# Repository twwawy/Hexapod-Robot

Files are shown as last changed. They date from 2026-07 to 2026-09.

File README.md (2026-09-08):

<div align="center">

# 모듈형 재난대응 6족 로봇

### Physical AI 기반 험지 이동·환경 인식·임무 확장 플랫폼







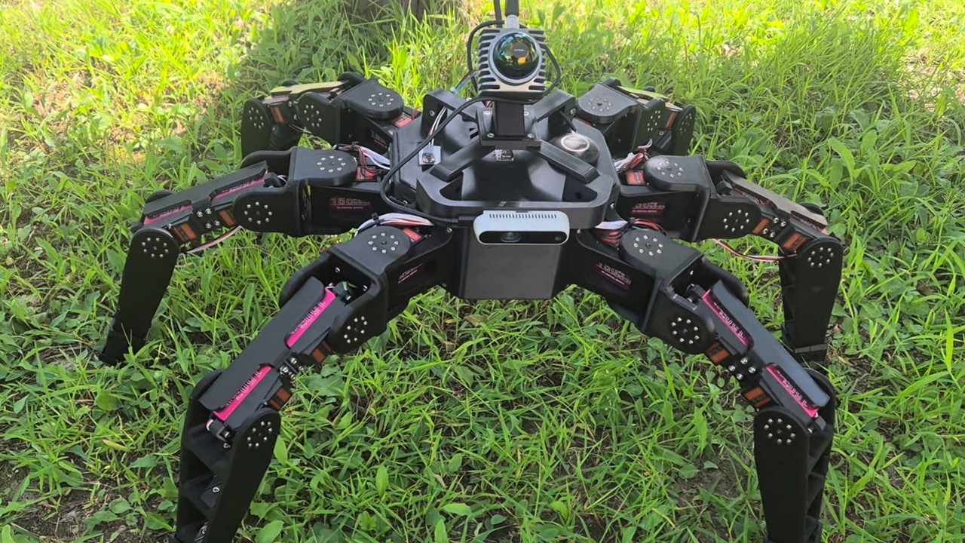
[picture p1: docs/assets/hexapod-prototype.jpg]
모듈형 재난대응 6족 로봇 시제품


</div>

## 통합 v4: 시작과 문서

**조종기 전제 학습 추가: [RC 명령 추종 학습](docs/ADAPTIVE_RC_TRAINING.md)**.
`--profile rc`는 전진·후진·yaw·정지 전환을 학습하며 command 성공과 계단 완주를 구분한다.
현재 RC curriculum은 평지 Tripod/Wave/Hybrid이다. 지형 등판과 혼합한 실기 조종 성능은 미검증이다.
RC 첫 학습은 기존 계단 checkpoint의 `--restore` 없이 시작한다. curriculum shell 명령은
commit별 독립 worktree에서 실행하여 개발 중 코드 변경이 다음 retry에 섞이지 않게 한다.

**최신: [phase 경계 재접촉 복구·70% 통과까지 재시도](docs/ADAPTIVE_RECONTACT.md)**.
MJX에서 대기 중 접촉이 끊긴 발만 제한적으로 내려 복구한다. GT 높이 계산/잔차 범위는
유지한다. curriculum 기본값은 완주율 70%를 통과해야 다음 지형으로 진행하며 무제한 재시도를 지원한다.

**현재 추천 학습: [GT teacher curriculum](docs/ADAPTIVE_GT_TEACHER.md)**.
정확한 지형으로 먼저 학습하고 cycle마다 zero-action/best-policy를 같은 seed로 비교한다.
기존 cycle별 W&B best score/영상은 유지한다. 실행은 사용자에게 맡긴다.
경사면 기존 checkpoint에서 [완주 보상으로 재개](docs/ADAPTIVE_COMPLETION_REWARD.md)할 수 있다.
잔차 범위 유지, 완주율 우선 best 선택, 최대 40초 영상과 마지막 5초 진단,
재시도·승급 정책은 위 최신 재접촉 문서의 70% 통과 기준을 따른다.

**최신 변경: elevation grid CNN 관측 v5** — 24-D 물리 action/SPI는 v4를 유지하지만,
정책은 24×24×6 로컬 지도를 CNN으로 읽는다. 지도 극값 누적·보폭 선호 때문에 발생하는
HOLD를 수정하고 보행 전환 지속 확인과 W&B 정지 시간 지표를 추가했다.
**기존 checkpoint와 입력/network가 달라 새 학습이 필요하다. 이번 변경의 학습·시뮬레이션은
실행하지 않았다.** [변경 범위·새 학습 명령·확인 항목](docs/ADAPTIVE_ELEVATION_GRID_V5.md)

현재 작업 브랜치 `codex/adaptive-hybrid-rl-integration`은 최신 main에서 시작해 adaptive MJX를
선택적으로 가져왔다. Full merge는 하지 않았다. **코드 통합과 portable 계약 검사까지 진행했으며,
계단 등판·PPO·STM32 보드 동작은 아직 검증하지 않았다.**

| 카테고리 | 문서 / 실행 경로 |
|---|---|
| 통합 architecture·24-D/관측·변경 내용·남은 위험 | [v4 통합 설명](docs/ADAPTIVE_INTEGRATION_V4.md) |
| 브랜치 분석·파일 출처 | [사전 분석](docs/ADAPTIVE_INTEGRATION_ANALYSIS.md), [전체 변경 파일](docs/ADAPTIVE_INTEGRATION_FILES.md) |
| Stage0 viewer·표시·조작 | [viewer 사용법](docs/HEXAPOD_MJX_ADAPTIVE_GAIT_USAGE.md) |
| 학습 단계 | [학습 계획](docs/HEXAPOD_MJX_ADAPTIVE_GAIT_LEARNING_PLAN.md) |
| 짧은 평지 cycle 반복·cycle별 W&B score/영상 | [실행 명령 및 저장 규칙](docs/ADAPTIVE_OBSERVE_CYCLES.md) |
| Rough hfield 오류 수정·평지 가중치에서 재개 | [adaptive box 지형과 명시적 이전](docs/ADAPTIVE_ROUGH_BOXES.md) |
| 수 회 Tripod 후 정지·영상 종료 수정 | [원인·수정·사용자 검증 명령](docs/TRIPOD_STOP_FIX.md) |
| Jetson ↔ STM32 wire | [SPI v3](docs/ADAPTIVE_SPI_V3.md) |
| STM32 실제 contact/Wave 기준 | [Wave gait](SW/STM32/WAVE_GAIT.md) |
| 기존 18-D replay | `scripts/view_trained_policy.sh`, 기존 `mjx/firmware_mjx_controller.py` |

```bash
cd /home/huro/Hexapod-Robot-integration
source /home/huro/.venvs/hexapod-mjx/bin/activate
bash scripts/view_foothold_planner.sh --controller adaptive --terrain flat --perception oracle
bash scripts/view_foothold_planner.sh --controller adaptive --terrain steps --perception oracle
bash scripts/view_foothold_planner.sh --controller adaptive --terrain steps --perception lidar --stage0 --speed 0.04
```

먼저 flat의 zero-action Tripod, 계단의 candidate/reference/selected/latched marker,
short-step·Wave 전환과 unknown HOLD를 확인한다. 이후 학습/오프라인 Jetson/ARM 빌드는
[순서별 명령](docs/ADAPTIVE_INTEGRATION_V4.md#사용자-실행-순서)을 사용한다.
방향키 포커스 문제가 있으면 `W/S`로 전후, `A/D`로 회전할 수 있다. 키가 들어오면 콘솔에
`command: vx=...`가 즉시 출력된다. `--speed 0.04`는 키 입력 없이 시작 명령을 넣는다.

## 프로젝트 소개

본 프로젝트는 붕괴 구조물, 잔해, 경사면, 단차와 계단처럼 사람이 직접 접근하기 어려운 재난 현장을 선행 탐색하기 위한 6족 보행 로봇이다. 하나의 공통 보행 플랫폼 위에 센서와 작업 장비를 교체할 수 있는 모듈형 구조를 적용하여, 환경 매핑·자율 탐색·현장 조작·구호물품 전달 등 임무별 구성을 목표로 한다.

6개의 독립적인 3자유도 다리와 총 18개의 관절을 사용하며, **Geometry가 지형과 가능한 영역을 계산하고, 강화학습이 foothold·clearance·몸체 자세/높이·보폭·trajectory timing을 최적화하며 STM32가 접촉과 실행 안전을 담당하는 계층형 제어 구조**를 채택하였다. Jetson은 SLAM·환경 인식·경로계획·강화학습 등 상위 연산을, STM32는 200 Hz 주기의 발끝 궤적·역기구학·서보 제어를 담당하도록 분리하였다.

> [!NOTE]
> 이 저장소는 구현 코드, 설계 자료, 시뮬레이션 결과와 개발 문서를 함께 관리한다. 기능별 완성도와 검증 수준이 다르므로 아래의 **현재 구현 상태**와 각 문서의 검증 범위를 확인해야 한다.

## 핵심 특징

| 영역 | 주요 내용 |
|---|---|
| **험지 보행** | Tripod Gait, 3차 Bézier 발끝 궤적, 3자유도 역기구학, 18개 서보모터 제어 |
| **접촉 적응** | 6개 FSR 접촉 상태 기반 Early Landing·Late Landing 보정과 작업영역 제한 |
| **계층형 Physical AI** | Classical Controller의 발끝 목표에 제한된 Cartesian Residual을 더하는 강화학습 구조 |
| **환경 인식** | Livox MID-360, RealSense D435, IMU를 이용한 3차원 인식·SLAM·경로계획 구조 |
| **분산 제어** | Jetson 상위 판단과 STM32 실시간 보행 제어 분리, 128바이트 SPI v3 실행/관측 프레임 |
| **모듈형 임무 확장** | 센서 위치 변경, 열화상·가스 센서, 매니퓰레이터, 구급·적재 모듈 확장 고려 |
| **원격 운용** | 위치·자세·통신·이동 경로 모니터링과 목적지·모드·비상 정지 명령 구조 |

## 시스템 구성

<div align="center">
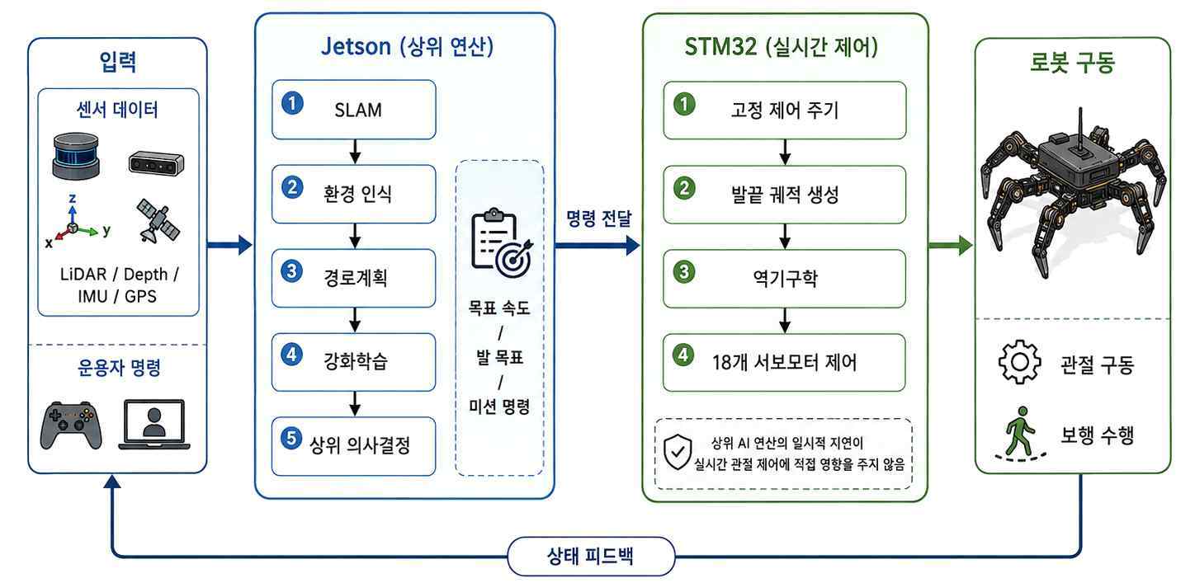
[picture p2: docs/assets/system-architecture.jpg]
Jetson과 STM32 기반 분산 제어 시스템 구조
  
</div>

```text
LiDAR / Depth Camera / IMU / 운용자 명령
                    │
                    ▼
Jetson Orin Nano Super
SLAM → 환경 인식 → 경로계획 → 강화학습·상위 의사결정
                    │  목표 속도·발 목표·임무 명령
                    ▼
STM32 NUCLEO-F446RE
고정 제어 주기 → 발끝 궤적 → 3DOF IK → 18개 서보 제어
                    │
                    ▼
              6족 로봇 구동
                    │  관절각·접촉·IMU 상태
                    └──────────────────────► Jetson / 관제 시스템
```

### STM32 ↔ Jetson 통신

통합 브랜치는 **SPI v3, 128 bytes**를 기본으로 사용한다. 최종 AdaptiveExecutionPlan을
explicit little-endian fixed point로 전달하고 CRC·session·sequence·observation age·plan을 검증한다.
상태와 계획 상세는 같은 시점의 두 observation page로 제공한다. 기존 v2 codec은 보존하지만
v2 master와 기본 v3 app은 호환되지 않는다. 실제 DMA/DRDY 운용은 사용자 검증 대상이다.

- [SPI v3 정확한 offset·단위·CRC](docs/ADAPTIVE_SPI_V3.md)
- [기존 v2 문서](SW/STM32/STM32-Jetson%20SPI%2032바이트%20패킷%20프로토콜.md)

## 보행 및 지형 적응 제어

### 1. Classical Controller

세 다리가 지면을 지지하는 동안 나머지 세 다리를 이동시키는 Tripod Gait를 사용한다. 스윙 발의 경로는 3차 Bézier 곡선으로 생성하고, 발끝 목표 좌표를 각 다리의 3자유도 역기구학으로 관절 목표각으로 변환한다. 작업영역과 IK 유효성을 검사하여 비정상적인 관절 명령이 출력되지 않도록 제한한다.

### 2. FSR 접촉 보정

- **Early Landing:** 예상보다 먼저 접촉하면 스윙을 종료하고 지지 상태로 전환
- **Late Landing:** 예정된 착지 시점에도 미접촉이면 발끝을 추가 하강하여 지면 탐색
- **기준 높이 보정:** 접촉 보정이 반복되어 몸체 높이가 누적 변화하지 않도록 기준값 보정

### 3. Adaptive residual policy 24-D v4

Wide25 후보에서 safe reference를 찾고, 별도 local25 후보에서 RL의 **X ±6 cm / Y ±4 cm**
요청을 안전한 endpoint로 projection한다. Terrain Z는 geometry가 결정한다.
6개 clearance, roll/pitch/body height, stride 및 apex/transfer timing도 policy가 조절한다.
Supervisor는 **Tripod normal → short-step → Wave → HOLD** 순서로 결정한다.
UNKNOWN은 즉시 Wave로 보내지 않는다. 학습 가중치 없이 zero-action Stage0부터 확인한다.

## 모듈형 재난 대응 시나리오

하나의 6족 플랫폼을 임무에 맞춰 재구성하는 것이 프로젝트의 핵심 방향이다.

| 구성 | 역할 | 현재 범위 |
|---|---|---|
| **LiDAR·IMU 모듈** | 3D 지도 생성, 위치·자세 추정, 자율 탐색 | 하드웨어·시스템 구조 개발 |
| **센서 위치 변경** | 고정형 LiDAR의 사각지대 보완, 목적별 공간 정보 수집 | 장착 구조 확장 방향 |
| **매니퓰레이터** | 문 개방, 가벼운 장애물 이동, 현장 작업 | 확장 모듈·실물 통합 검증 필요 |
| **구급·적재 모듈** | 구급상자, 센서와 필수 물품 전달 | 확장 제안 |
| **열화상·가스 센서** | 인명·열원 탐색, 유해 환경 측정 | 확장 제안 |

```text
현장 투입 → 환경 인식·지도 생성 → 통과 가능성 판단
         → 자율주행·험지 이동 → 현장 조작 또는 물자 전달
         → 상태 보고·필요 시 원격 개입
```

## 현재 구현 및 검증 상태

| 항목 | 상태 | 검증 범위 |
|---|---|---|
| 6족 기구·18자유도 구동부 | 제작 | Fusion 360, 분리형 다리·몸체·센서 장착부 |
| STM32 기본 보행 제어 | 구현 | Tripod Gait, Bézier 궤적, IK, Safety, FSR 접촉 처리 |
| STM32 실시간 로깅 | 구현 | 접촉 상태, 보행 Phase, 발끝 목표, IK 결과, 관절 목표각 |
| STM32–Jetson 상태 통신 | STM32 측 구현 | SPI v3 codec/app 연결, 실제 DMA/DRDY는 미검증 |
| MATLAB/Simulink 제어 시험 | 실행·기록 | 몸체 고정 모델의 0–81 s 단일 시험, 실제 자유 보행 성능 아님 |
| Isaac Sim·MuJoCo | 시뮬레이션 구성 | 보행·Residual-RL 학습 구조, 실물 성능과 별도 검증 필요 |
| Jetson SLAM·자율주행 | 설계·통합 대상 | geometry bridge·zero-action·SPI codec 구현, live 센서/odom 연결은 별도 |
| 원격 관제·LoRa | 시스템 설계 | 실시간 현장 운용 성능은 별도 검증 필요 |

### 공개된 Simulink 시험 결과

2026-08-31에 기존 `plant.slx`를 MATLAB R2026a Update 3에서 실행한 결과다. 몸체가 월드에 고정된 관절·기구학 제어 시험이므로 실제 험지 주행 성능으로 해석하면 안 된다.

| 평가 항목 | 결과 |
|---|---:|
| 6개 다리 통합 발끝 RMS 거리 오차 | **3.385 mm** |
| 발끝 최대 거리 오차 | **8.631 mm** |
| 18개 관절 통합 RMS 오차 | **0.4004°** |
| 6개 다리 IK 유효 표본 비율 | **100%** |

<div align="center">
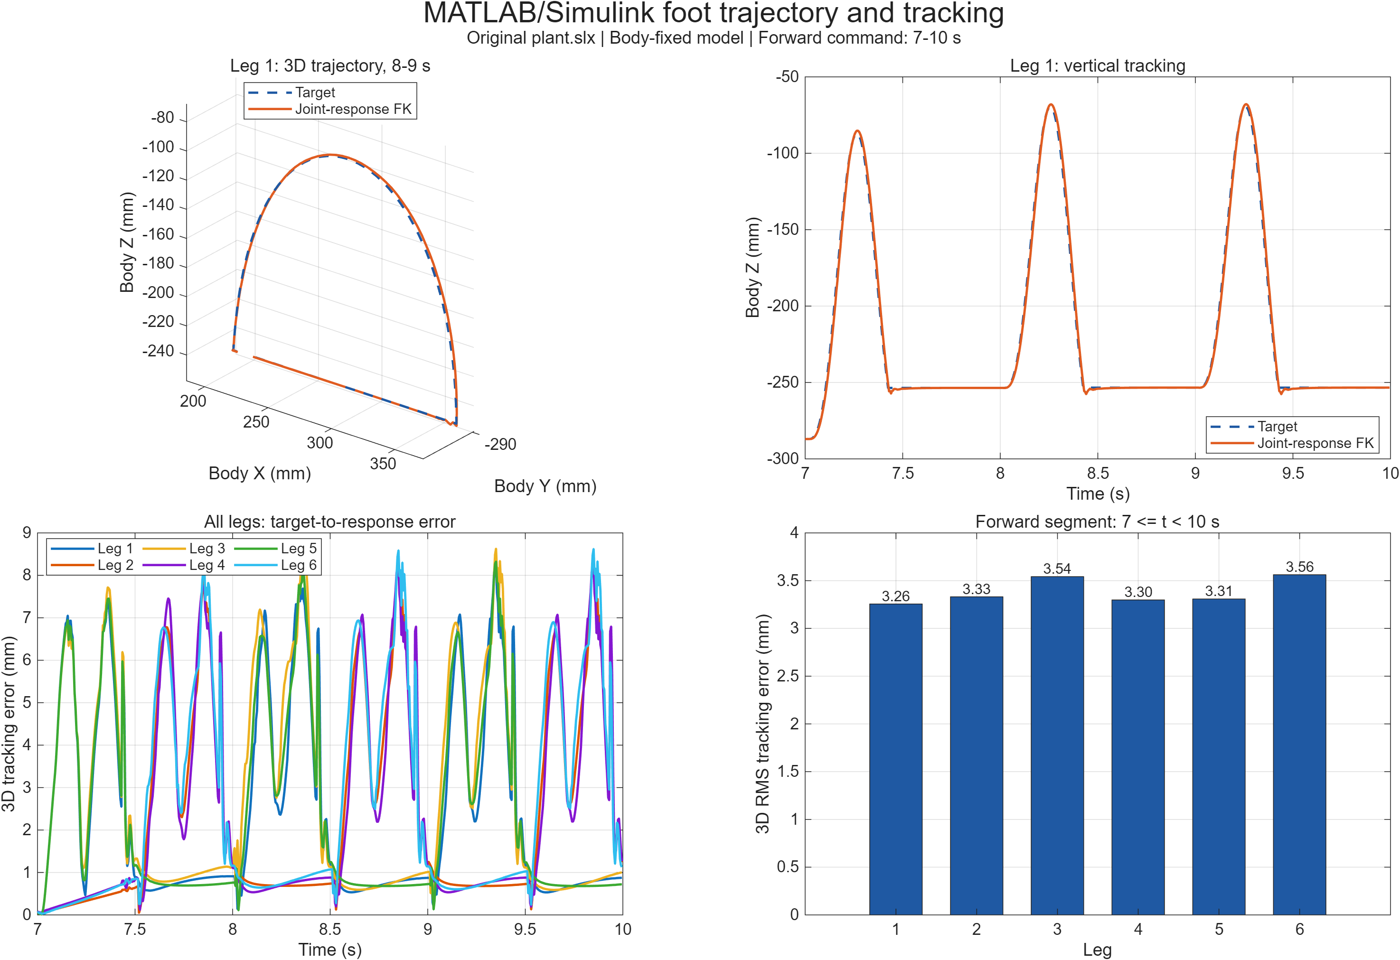
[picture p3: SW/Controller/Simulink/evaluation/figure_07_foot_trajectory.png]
MATLAB Simulink 발끝 궤적 및 추종 결과
  
</div>

자세한 조건, 원시 데이터와 재현 절차는 [MATLAB/Simulink 실행 결과](SW/Controller/Simulink/evaluation/RESULTS.md)를 참고한다. 평지 10 m 보행 성공률, 실제 평균 보행 속도, 최대 단차·경사, 계단 통과율, 실제 경로 추종 오차와 Residual-RL 전후 비교는 현재 공개 자료만으로 확정하지 않았으며 임의 수치를 제시하지 않는다.

## 저장소 구성

```text
Hexapod-Robot/
├─ HW/
│  ├─ PCB/                  # PCB Gerber·Drill 자료
│  ├─ stl_file/             # 3D 프린팅용 STL
│  ├─ gcode_file/           # G-code·3MF
│  └─ urdf/                 # 현재 URDF·시뮬레이션 설정
├─ SW/
│  ├─ Controller/           # 보행 제어 수식·좌표계·Simulink
│  ├─ STM32/                # STM32CubeIDE 펌웨어·통신 문서
│  └─ Jetson/               # 상위 제어 범위·인터페이스 문서
└─ docs/
   ├─ assets/               # README 이미지
   └─ 2026-inha-capstone-final-report-public.pdf
```

## 주요 문서

- [2026 인하 종합설계경진대회 최종보고서 - 공개용](docs/2026-inha-capstone-final-report-public.pdf)
- [하드웨어 구성 및 제작 자료](HW/README.md)
- [하드웨어 부품 목록](HW/parts.md)
- [제어기 Architecture](SW/Controller/Controller_Architecture.md)
- [제어기 상세 설계](SW/Controller/Controller_detail.md)
- [좌표계와 관절 정의](SW/Controller/좌표축/README.md)
- [STM32F446RE 설정](SW/STM32/STM32F446RE%20설정%20정리본.md)
- [STM32 코드 구조](SW/STM32/STM32%20코드%20구조%20정리본.md)
- [STM32–Jetson SPI 프로토콜](SW/STM32/STM32-Jetson%20SPI%2032바이트%20패킷%20프로토콜.md)
- [매니퓰레이터 UART 프로토콜](SW/STM32/Manipulator_UART_Protocol.md)
- [Jetson 소프트웨어 범위](SW/Jetson/README.md)
- [Simulink 평가 결과 및 재현 절차](SW/Controller/Simulink/evaluation/RESULTS.md)

## 주의 사항

- 고토크 서보모터와 LiPo 배터리를 사용하는 시스템이므로 전원·배선·비상 정지 절차를 먼저 확인해야 한다.
- 소스 코드, 빌드 결과물, 실제 보드에 플래시된 펌웨어와 실물 시험 결과는 서로 다른 검증 단계다.
- 보고서와 시뮬레이션의 미평가 항목은 실패나 0%를 뜻하지 않으며, 반복 실물 시험 후 수치화해야 한다.

---

<div align="center">

**One hexapod platform, multiple disaster-response missions.**

</div>

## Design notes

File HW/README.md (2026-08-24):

# 하드웨어 구성

Jetson Orin Nano Super와 STM32 NUCLEO-F446RE를 기반으로 제작하는 6족 보행 로봇 프로젝트입니다.

Jetson Orin Nano Super는 LiDAR와 Depth Camera를 이용한 인지·자율주행을 담당하고, STM32 NUCLEO-F446RE는 센서 수집, 200 Hz 보행 제어, 서보·릴레이 출력과 통신을 담당한다.

## 주요 구성

| Category | Main Parts |
|---|---|
| Main Computer | Jetson Orin Nano Super |
| MCU | STM32 NUCLEO-F446RE |
| Controller | RadioMaster Pocket ELRS |
| Actuator | DS51150-270 Servo Motor |
| LiDAR | Livox Mid-360 |
| Depth Camera | Intel RealSense D435 |
| IMU | WT931 9DOF IMU |
| GPS | NEO-M8N GPS Module |
| Communication | RYLR998 LoRa Module |
| Battery | 3S / 2S 7200mAh Battery |
| Frame | 3D Printed PLA Parts |

자세한 수량과 구매 정보는 [부품 목록](parts.md), STM32 핀과 주변장치 설정은 [STM32F446RE 설정 정리본](../SW/STM32/STM32F446RE%20설정%20정리본.md)을 참고한다.

기구와 제작 자료는 다음 폴더에 있다.

| 경로 | 내용 |
|---|---|
| [stl_file](stl_file) | 3D 프린팅용 STL |
| [gcode_file](gcode_file) | 출력용 G-code와 3MF |
| [PCB](PCB) | PCB Gerber와 Drill 파일 |
| [urdf](urdf) | 현재 URDF와 시뮬레이션 설정 |
| [urdf_earlyVersion](urdf_earlyVersion) | 초기 URDF 보관본 |

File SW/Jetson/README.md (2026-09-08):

> 통합 v4: 현재 구현·남은 연결 작업은 [통합 문서](../../docs/ADAPTIVE_INTEGRATION_V4.md), wire는 [SPI v3](../../docs/ADAPTIVE_SPI_V3.md)를 참고하세요. 아래 기존 설계 설명과 구분합니다.

# Jetson 소프트웨어

Jetson Orin Nano Super에서 담당할 상위 인지·자율주행 소프트웨어의 범위를 정리한다. 현재 이 폴더에는 실행 코드가 없지만 STM32 센서 패킷 규격과 Slave DMA 전송 경로는 구현되어 있다.

## 예정 역할

- Livox Mid-360과 RealSense D435 데이터 수집
- 지형·장애물 인식
- 경로 계획과 자율주행 명령 생성
- STM32 상태 수신과 상위 상태 관리

Jetson은 5 ms 관절 제어와 서보 PWM을 직접 수행하지 않는다. 실시간 보행 궤적, IK, Safety와 액추에이터 출력은 STM32가 담당한다.

## STM32 연결

Jetson은 SPI Master, STM32는 SPI2 Slave로 사용한다. MOSI, MISO, SCLK, CS와 DRDY 물리 연결은 [STM32F446RE 설정 정리본](../STM32/STM32F446RE%20설정%20정리본.md#6-jetson-orin-nano-super--stm32-통신)을 따른다.

현재 STM32에 확정·구현된 항목은 다음과 같다.

- SPI Mode 0 기반 64바이트 전이중 트랜잭션 v3
- MISO Byte 0~31의 SENSOR Subframe: 18개 관절각, 6개 발 접촉과 IMU 자세
- MISO Byte 32~63의 GPS Subframe: 위도, 경도, 고도, GPS 시각, 수평 속도와 정확도
- CRC-16/CCITT-FALSE와 16비트 Sequence
- STM32 SPI2 Slave RX/TX DMA
- STM32가 DMA를 Arm한 뒤 `DRDY` High, 완료 또는 오류에서 Low
- Jetson의 64바이트 `0x00` Dummy 읽기 허용

Jetson이 보낼 `COMMAND`는 MOSI 64바이트 전체를 사용하며, STM32는 헤더와 전체 CRC를 검증한 뒤 Raw 56바이트 Payload를 보관한다. 다만 Payload 내부 명령 배치, 명령 Timeout, 자율주행·수동 조종 전환과 Safety 우선순위 연결은 아직 정하지 않았다.

정확한 필드 배치, 인코딩, CRC와 거래 순서는 [STM32–Jetson SPI 패킷 프로토콜](../STM32/STM32-Jetson%20SPI%2032바이트%20패킷%20프로토콜.md)을 따른다. Jetson 구현은 먼저 1 MHz에서 `DRDY`를 기다린 뒤 한 CS 구간에서 정확히 64바이트를 교환하고 SENSOR와 GPS의 CRC를 각각 검증해야 한다.

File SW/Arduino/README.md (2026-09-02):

# Hexapod 매니퓰레이터 Arduino 제어

이 디렉터리는 Hexapod-Robot에 장착된 6축 매니퓰레이터를 Arduino Uno로 제어하는 펌웨어를 관리한다. Uno는 STM32가 보내는 조종기 패킷을 받아 6개 PWM 서보를 구동하며, 조종기 연결·Motion Armed·ARM 모드가 모두 유효할 때만 목표 자세를 갱신한다.

현재 소스는 Arduino Uno 컴파일까지 확인했다. 실제 로봇에서의 전원 인가, 전 관절 동작 범위, 링크 길이와 충돌 한계는 별도 실기 검증이 필요하다.

## 디렉터리 구성

| 경로 | 용도 |
|---|---|
| [`ManipulatorController/ManipulatorController.ino`](ManipulatorController/ManipulatorController.ino) | STM32 패킷 수신, 안전 조건 검사, 부팅 자세 정렬, 역기구학 및 6축 서보 제어 |
| [`ManipulatorController/README.md`](ManipulatorController/README.md) | 제어기 내부 설정과 패킷 처리 상세 |
| [`ManipulatorCalibration/ManipulatorCalibration.ino`](ManipulatorCalibration/ManipulatorCalibration.ino) | J1~J6 소프트웨어 영점 조정 및 Uno EEPROM 저장 |

관련 STM32 문서는 다음과 같다.

- [매니퓰레이터 UART 패킷 명세](../STM32/Manipulator_UART_Protocol.md)
- [드론 조종기 입력 및 ARM 모드](../Controller/드론%20조종기%20입력/README.md)

## 하드웨어 구성

현재 핀과 관절 배치는 다음과 같다.

| 관절 | 기능 | 서보 | Uno 신호 핀 | 기본 영점 |
|---|---|---|---:|---:|
| J1 | 베이스 회전 | DS51150-270 | D5 | 1290 µs |
| J2 | 어깨 | DS51150-270 | D6 | 1600 µs |
| J3 | 팔꿈치 | DS51150-270 | D7 | 1480 µs |
| J4 | 손목 Pitch | DS51150-270 | D8 | 1510 µs |
| J5 | 손목 Roll | SPT5435LV-180 | D9 | 1610 µs |
| J6 | 그리퍼 | SPT5435LV-180 | D10 | 1540 µs |

위 영점은 현재 조립 상태에서 얻은 소프트웨어 기준값이다. 기구 분해, 혼 재체결 또는 서보 교체 후에는 다시 캘리브레이션해야 한다.

## 전원 및 신호 배선

서보 전류를 Arduino Uno에서 공급하면 안 된다. 현재 구성은 서보 종류별 외부 전원과 공통 신호 접지를 사용한다.

```text
STM32 PC12 / UART5_TX ─────────────> Uno D0 / RX
STM32 GND ───────────────┬─────────> Uno GND
                        ├─────────> DS 전원 GND
                        └─────────> SPT 전원 GND

외부 DS 전원 + ───────────────────> J1~J4 전원 +
외부 SPT 전원 + ──────────────────> J5~J6 전원 +
Uno D5~D10 ───────────────────────> J1~J6 PWM 신호
```

전원 연결 시 다음 원칙을 지킨다.

1. J1~J4와 J5~J6의 양극 전원은 서로 분리한다. 현재 사용 중인 정확한 서보 모델의 라벨과 데이터시트에서 허용 전압을 다시 확인한다.
2. STM32, Uno와 두 서보 전원의 GND는 PWM 기준 전압을 위해 공통으로 연결한다.
3. 서보 부하 전류는 Uno GND 핀이나 브레드보드 전원 레일을 경유하지 않고 전원 분배점으로 직접 귀환시킨다.
4. Uno의 5 V 핀과 디지털 핀에서는 서보 전원을 공급하지 않는다.
5. 코드 업로드와 캘리브레이션 중에는 STM32 TX선을 Uno D0에서 분리한다. Uno의 USB-UART와 STM32 TX가 동시에 D0을 구동하지 않게 한다.

## 전체 동작 흐름

```text
전원 인가
  → EEPROM 영점 확인
  → J1~J6 순차 활성화
  → 직립 영점으로 저속 이동
  → 영점에서 2초 유지
  → 접힌 READY 자세로 이동
  → 마지막 자세 유지
  → 정상 패킷 + 안전 Flags 0x07 + SC=1
  → 조종기 입력으로 매니퓰레이터 제어
```

부팅 자세 정렬은 통신 상태와 관계없이 한 번 실행된다. 이후 ARM 조건이 해제되거나 패킷이 100 ms 이상 끊기면 원점 복귀나 PWM 해제를 하지 않고 마지막 목표 자세를 유지한다.

일반 PWM 서보에는 현재각 피드백이 없으므로, Uno는 전원 인가 당시의 실제 관절 위치를 알 수 없다. 전원이 꺼진 상태에서 팔을 임의로 움직였다면 첫 PWM 출력에서 예상보다 빠른 움직임이 생길 수 있다. 첫 시험에서는 팔을 받침대로 지지하고 비상 전원 차단이 가능한 상태를 유지한다.

## 캘리브레이션

캘리브레이션 스케치는 J1(D5)부터 J6(D10)까지 한 축씩 조정한다. 각 관절은 기존 실측 영점에서 시작하며 `1000~2000 µs` 범위에서 `10 µs`씩 조절한다.

### 실행 순서

1. STM32 TX선을 Uno D0에서 분리한다.
2. [`ManipulatorCalibration.ino`](ManipulatorCalibration/ManipulatorCalibration.ino)를 Arduino Uno에 업로드한다.
3. 시리얼 모니터를 `115200 baud`, `Newline` 또는 `Both NL & CR`로 연다.
4. 현재 관절을 `up` 또는 `down`으로 움직인다.
5. 기구학적 영점에 도달하면 `ok`를 입력한다.
6. J6까지 같은 절차를 완료한다.
7. 마지막에 출력되는 `HOME_US={...}` 값을 기록한다.
8. [`ManipulatorController.ino`](ManipulatorController/ManipulatorController.ino)를 다시 업로드한다.
9. 제어기 부팅 시 출력되는 `HOME_US={...}`가 캘리브레이션 결과와 같은지 확인한다.

### 명령

| 명령 | 동작 |
|---|---|
| `up` | 현재 PWM을 10 µs 증가 |
| `down` | 현재 PWM을 10 µs 감소 |
| `ok` | 현재 관절값을 확정하고 다음 관절로 이동 |

EEPROM에는 Magic, Version과 J1~J6 값이 함께 저장된다. J6까지 완료한 뒤 유효 표시를 마지막으로 기록하므로 중간에 전원이 꺼진 불완전한 보정값은 제어기가 사용하지 않는다. 유효한 기록이 없으면 소스에 포함된 기본 영점 `{1290,1600,1480,1510,1610,1540}`를 사용한다.

캘리브레이션 중 관절이 기계적 끝단에 닿거나, 링크가 비틀리거나, 서보가 지속적으로 진동하거나, 배선이 뜨거워지면 즉시 서보 전원을 차단한다.

## STM32 통신

STM32 `UART5_TX/PC12`에서 Uno `D0/RX`로 `115200 baud, 8-N-1` 단방향 통신을 사용한다. STM32는 5 ms 주기로 16바이트 패킷을 전송한다.

| Byte | 필드 | 형식 |
|---:|---|---|
| 0 | Sync 0 | `0xA5` |
| 1 | Sync 1 | `0x5A` |
| 2 | Version | `0x01` |
| 3 | Sequence | `uint8_t` |
| 4 | Flags | `uint8_t` |
| 5 | Switches | `uint8_t` |
| 6~7 | Roll | `int16_t`, little-endian |
| 8~9 | Pitch | `int16_t`, little-endian |
| 10~11 | Throttle | `int16_t`, little-endian |
| 12~13 | Yaw | `int16_t`, little-endian |
| 14~15 | CRC-16/CCITT-FALSE | little-endian |

CRC는 Byte 0~13에 대해 Polynomial `0x1021`, Initial value `0xFFFF`, XorOut `0x0000`으로 계산한다. Uno는 Sync, Version, CRC와 중복 Sequence를 검사한 정상 패킷만 적용한다.

## ARM 허가 조건

다음 조건이 모두 참이어야 조종 명령이 적용된다.

- Flags bit 0: Controller connected
- Flags bit 1: Motion armed
- Flags bit 2: STM32 ARM mode allowed
- Switches의 SC 값이 `1`
- 마지막 정상 패킷 수신 후 100 ms 이내
- 부팅 영점 및 READY 자세 이동 완료

즉, 정상 안전 Flags는 `(flags & 0x07) == 0x07`이며 SC도 별도로 확인한다.

## 조종기 매핑

| 입력 | 기본 동작 | SA 활성 상태 |
|---|---|---|
| Roll | 베이스를 이용한 말단 y축 이동 | 동일 |
| Pitch | 말단 x축 전진·후진 | 동일 |
| Throttle | 말단 z축 상승·하강 | 그리퍼 비례 개폐 |
| Yaw | 손목 Roll 회전 | 동일 |
| SA | 해제 시 일반 제어 | 누르는 동안 Throttle을 그리퍼로 전환 |
| SC | `1`일 때 ARM 모드 | 동일 |

SA를 누른 동안 Throttle 최저는 그리퍼 열림, 최고는 닫힘으로 매핑되며 z축 이동은 멈춘다. SA를 놓으면 마지막 그리퍼 각도를 유지하고 Throttle은 다시 z축 이동에 사용된다.

Pitch와 Throttle은 J2·J3의 평면 Jacobian 역기구학으로 x·z 속도로 변환한다. J4는 J2와 J3 움직임을 보정해 READY 자세의 말단 Pitch를 유지한다. 입력에는 데드밴드, 저역통과 필터와 관절별 PWM Slew Limit를 적용한다.

## 주요 제어 설정

| 설정 | 현재값 | 의미 |
|---|---:|---|
| `LINK1_MM` | 300 mm | 어깨-팔꿈치 축간거리 임시값 |
| `LINK2_MM` | 300 mm | 팔꿈치-손목 축간거리 임시값 |
| `MAX_XZ_SPEED_MM_S` | 90 mm/s | 말단 x·z 최대 명령 속도 |
| `MAX_Y_SPEED_MM_S` | 70 mm/s | 말단 y 최대 명령 속도 |
| `MAX_WRIST_SPEED_DEG_S` | 50 deg/s | 손목 최대 회전 속도 |
| `AXIS_DEADBAND` | 35 | 조종기 입력 데드밴드 |
| `PAYLOAD_TIMEOUT_MS` | 100 ms | 패킷 Freshness 제한 |
| `READY_DEG` | `{0,35,-100,-25,0,0}` | 현재 접힌 READY 자세 |

`LINK1_MM`, `LINK2_MM`, READY 자세와 관절 한계는 현재 실측 Fusion 값이 아닌 보수적 설정을 포함한다. 최종 운용 전에 실제 축간거리와 충돌 없는 관절 범위로 갱신해야 한다.

## 빌드 및 업로드

Arduino IDE에서는 보드를 `Arduino Uno`로 선택하고 각 스케치 폴더와 같은 이름의 `.ino` 파일을 연다. CLI 환경에서는 다음처럼 컴파일할 수 있다.

```powershell
arduino-cli compile --warnings all --fqbn arduino:avr:uno SW/Arduino/ManipulatorCalibration
arduino-cli compile --warnings all --fqbn arduino:avr:uno SW/Arduino/ManipulatorController
```

업로드 전에는 STM32 TX선을 Uno D0에서 분리한다. 제어기 업로드가 끝난 뒤 전원을 끈 상태에서 `STM32 PC12 → Uno D0`, `STM32 GND → Uno GND`를 다시 연결한다.

## 시리얼 진단

제어기는 0.5초마다 다음 형식의 상태를 출력한다.

```text
DBG bytes=0 ok=0 verErr=0 crcErr=0 dup=0 ageMs=NONE ready=1 flags=0x0 sw=0x0 SC=0 SA=0 safety=0 arm=0 allow=0 R=0 P=0 T=0 Y=0
```

| 항목 | 의미 |
|---|---|
| `bytes` | Uno D0에서 읽은 누적 바이트 수 |
| `ok` | Version과 CRC를 통과한 정상 패킷 수 |
| `verErr` | Version 오류 패킷 수 |
| `crcErr` | CRC 오류 패킷 수 |
| `dup` | 중복 Sequence 수 |
| `ageMs` | 마지막 정상 패킷 이후 경과 시간 |
| `ready` | 부팅 READY 자세 도달 여부 |
| `safety` | Flags bit 0~2 허가 여부 |
| `arm` | SC가 1인지 여부 |
| `allow` | 현재 조종 입력 적용 여부 |

`bytes=0`이면 CRC보다 먼저 물리 경로를 확인한다. STM32 PC12 TX와 Uno D0 RX의 교차 연결, 공통 GND, UART5 핀 설정, 115200 baud, STM32 펌웨어 다운로드 여부를 점검한다. `bytes`는 증가하지만 `ok=0`이면 Sync, Version, 패킷 길이, 바이트 순서와 CRC 계산 범위를 확인한다.

Uno의 D0/D1은 USB-UART와 공유된다. USB 시리얼 모니터를 열면 Uno가 리셋되어 부팅 자세 정렬이 다시 실행될 수 있으며, 시리얼 모니터에서 문자를 전송하면 STM32 수신 데이터와 섞일 수 있으므로 진단 중에는 입력하지 않는다.

## 최초 실기 시험 체크리스트

1. 배터리를 분리한 상태에서 전원 양극과 GND 단락 여부를 확인한다.
2. 서보를 연결하기 전에 J1~J4 전원과 J5~J6 전원 전압을 각각 측정한다.
3. STM32, Uno와 서보 전원 GND가 공통인지 확인한다.
4. 캘리브레이션 스케치로 J1부터 한 축씩 연결하고 방향과 영점을 확인한다.
5. 제어기 업로드 후 서보 전원을 넣기 전에 출력된 `HOME_US`를 확인한다.
6. 팔을 받친 상태에서 부팅 영점 이동과 READY 이동을 확인한다.
7. ARM 진입 전 `bytes`, `ok`, `ready`, `flags`, `SC`를 확인한다.
8. SC를 `1`로 바꾼 뒤 작은 조종 입력부터 시험한다.
9. 각 축의 방향, 충돌 범위, 전원 전압 강하와 커넥터 발열을 기록한다.

## 문제 해결

### 서보가 드드드 진동하고 움직이지 않음

즉시 서보 전원을 끈다. 링크 또는 혼을 분리할 수 있으면 무부하 상태로 한 축만 시험하고, 증상 발생 중 서보 단자 전압을 측정한다. 정상 서보를 같은 핀에 연결하고 의심 서보를 정상 핀에 연결해 전원·신호·서보 자체 문제를 분리한다. 전압 강하, 기계적 끝단 구속, GND 불량, 커넥터 발열을 확인하기 전에는 서보 고장으로 단정하지 않는다.

### 전원 인가 직후 빠르게 튐

현재 PWM 서보에서 실제 시작 각도를 읽을 수 없기 때문이다. 마지막 종료 자세를 READY로 유지하고 팔을 받친 상태에서 전원을 넣는다. 임의 자세에서도 폐루프 저속 이동이 필요하면 관절 위치 피드백을 추가해야 한다.

### ARM 모드인데 움직이지 않음

`ready=1`, `ok` 증가, `ageMs≤100`, `flags`의 하위 3비트가 모두 1, `SC=1`, `allow=1`인지 순서대로 확인한다. 하나라도 만족하지 않으면 제어기는 안전하게 마지막 자세를 유지한다.

### 방향이 반대임

해당 관절의 `SERVO_DIRECTION[]` 부호를 바꾼다. 현재 설정은 J3만 `-1`이고 나머지는 `+1`이다. 변경 후 반드시 한 축씩 낮은 이동량으로 재시험한다.

## 검증 상태

| 항목 | 상태 |
|---|---|
| Arduino Uno 컴파일 | 통과 |
| STM32 16바이트 패킷 형식 대조 | 소스 및 명세 대조 완료 |
| J1~J6 EEPROM 캘리브레이션 연동 | 코드 구현 및 컴파일 완료 |
| 실제 6축 동시 구동 | 미검증 |
| 실제 링크 길이와 작업공간 | 실측 필요 |
| 장시간 부하·발열 시험 | 미검증 |

소스 컴파일 성공은 실제 기구의 안전한 동작을 보장하지 않는다. 최종 운용 전에는 한 축 시험, 무부하 시험, 전압 강하 확인, 제한각 설정과 비상 차단 시험을 완료해야 한다.

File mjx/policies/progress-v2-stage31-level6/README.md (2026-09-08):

# stage31 level6 학습 정책 실행

선택한 run은 `progress-v2-stage31-level6_20260828-111825_seed40`이다.
로컬 `mjx/runs/terrain/`에 있던 실제 Brax/Orbax checkpoint를 이 패키지에 포함했다.
W&B 로그나 GIF를 정책으로 사용하는 것이 아니라, 저장된 가중치와 관측 정규화 통계를 복원한다.

**착지점 뷰어 안에서 이 정책을 쓰는 기본 실행 명령:**

```bash
cd /home/huro/Hexapod-Robot
source /home/huro/.venvs/hexapod-mjx/bin/activate
bash scripts/view_foothold_planner.sh --terrain steps
```

이 명령은 기존 넓은 코스에서 미관측 첫걸음을 펌웨어 nominal/RL=0으로 시작한다.
관측이 생겨도 기본 제어기는 계속 보행하고 stage31 residual의 크기만 부드럽게 조절한다.
착지 후보는 참고 표시이며 실제 경로로 주입하지 않는다. `--residual-scale 0`은 같은 동역학의 기본 제어기 비교다.
이 모드의 지형 입력은 LiDAR 관측이며, 아래 별도 재생기의 원래 정책/시뮬레이터 관측 구성과 다르다.
자세한 조작법과 관측/제어의 구분은 [착지점 뷰어 안내](../../../docs/HEXAPOD_FOOTHOLD_PREVIEW_USAGE.md)를 따른다.
아래는 별도 `view_trained_policy.sh`의 run 지형 재현 모드 설명이다.

```bash
cd /home/huro/Hexapod-Robot
bash scripts/view_trained_policy.sh
```

가상환경은 `/home/huro/.venvs/hexapod-mjx`이다. 스크립트가 직접 사용하므로 activate는
선택 사항이다. 기존 JAX/MJX/Brax 학습 환경이 필요하며, 화면 표시만 가능한 MuJoCo 환경으로는
실행할 수 없다. 첫 실행은 JAX 컴파일로 시간이 걸릴 수 있다.

| 항목 | 값 |
|---|---|
| 선택 기준 | 해당 run의 `monitor/level_best_checkpoint.json` |
| checkpoint step | **1,703,936** (`000001703936`) |
| 기록된 평가 점수 | 171.364044; 저장된 점수이며 이번에 재평가하지 않음 |
| W&B project / run ID | `hexapod-real` / `9w1fzji2` |
| 입력 | 146-D observation + 저장된 정규화 통계 |
| 출력 | 18-D adaptive swing residual v3 |
| 네트워크 | 256 → 256 → 128, SiLU, deterministic inference |
| 지형 | 7단 × 6.5 cm, 총 높이 45.5 cm |
| 제어/물리 주기 | 20 ms / 2.5 ms |
| 기본 reset seed | 20040; best 영상 생성 코드의 training seed 40 + 20000 |
| 원본 코드 기준 | 기록된 Git revision `0805164a5db4e85f1039637c829b760e5bc3d87b` |

이 checkpoint는 level 최고 점수 기준이다. 기존 학습의 `best_safe` 기준 통과 모델을
선택했다는 뜻은 아니다. 선택 당시 평가 기록은 `recorded_score.json`에 그대로 포함한다.

## 구성과 조작

시뮬레이터 상태·지형 관측 → 저장된 정규화 → PPO 정책 → STM32 기반 gait/잔차 제한/IK →
MuJoCo MJX 동역학 순서로 진행한다. 박스 몸체·캡슐 링크·구형 발을 사용하는 학습 환경이다.
현재 `view_foothold_planner.sh`의 LiDAR 높이 지도·착지점 보정은 이 경로에 연결하지 않았다.
이 정책이 학습한 terrain 관측은 시뮬레이터에서 제공한다.

| 키 | 동작 |
|---|---|
| Space | 시뮬레이션 일시정지 / 재개 |
| R | 같은 seed와 원래 샘플된 command로 reset 후 실행 |
| ↑ / ↓ | 전진 command ±0.02 m/s, 범위 0~0.12 |
| ← / → | yaw command ±0.1 rad/s, 범위 ±0.3 |
| F | 로봇 추적 카메라 전환 |

처음에는 키 입력 없이 저장 설정으로 동작을 본다. 방향키를 누르면 command를 변경한
실험이 된다. 이 run의 학습 yaw 범위는 0이므로 회전 결과는 학습 범위 밖의 동작이다.
종료 조건이나 episode 길이에 도달하면 마지막 자세를 유지하고 원인을 표시한다. R로 다시 시작한다.
HUD의 `action norm`은 복원된 PPO가 출력한 action 크기다.

```bash
# 평지에서 정책 동작 비교
bash scripts/view_trained_policy.sh --terrain flat

# 정지 화면에서 시작하거나 재생 속도 조절
bash scripts/view_trained_policy.sh --paused --speed 0.5

# 다른 초기 난수 상태
bash scripts/view_trained_policy.sh --seed 40
```

## 코드와 기록의 차이

현재 작업 폴더의 v4 정책 계약을 이 checkpoint에 적용하지 않는다. 기록된 커밋의 코드와
URDF를 `mjx/generated/trained_policy/source-0805164a5db4/`에 추출해 별도로 import한다.
원본 커밋의 level6 계단은 10 cm지만 run 기록은 6.5 cm이므로, 저장된 지형 치수로
해당 level 정의를 대체한다. 나머지 설정은 `environment.json`에서 읽는다.

학습 당시 미커밋 소스 전체는 run에 보관되지 않았다. 기록된 reward 계약과 커밋의
reward 코드에도 차이가 있어, 이 실행은 **가중치와 기록 기반 환경의 복원**이다.
W&B 영상·점수·종료 시점의 완전한 재현을 확인한 것은 아니다.

현재 패키지 파일의 해시 확인과 소스 추출까지만 수행했다. 사용자 요청에 따라 가중치 로딩,
정책 추론, GUI 실행, 동역학 보행 검증은 수행하지 않았다.

`manifest.json`에는 출처·checkpoint·SHA-256을 기록했다. 실행 시의 소스 경로·seed·환경은
`mjx/generated/trained_policy/replay_manifest.json`에 기록한다. 이 패키지에는 새 학습이나
W&B 업로드를 수행하는 코드가 없다.

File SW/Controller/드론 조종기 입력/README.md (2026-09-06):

# 드론 조종기 입력

RadioMaster Pocket ELRS 조종기로 육각보행 로봇에 전달할 사용자 명령을 정의한다. 이 문서는 채널 배치, 입력값 규격, 모드별 조작법과 입력 보호 동작만 다룬다. 제어기 내부 계산은 [Controller_detail.md](../Controller_detail.md), 몸체 축의 정의는 [좌표축 README](../좌표축/README.md)를 따른다.

## 1. 사용 장비와 통신

| 항목 | 사양 |
|---|---|
| 조종기 | RadioMaster Pocket ELRS, Mode 2 |
| 수신기 | DarwinFPV 2.4G ELRS Nano |
| 무선 링크 | ELRS 2.4 GHz |
| 수신기 출력 | CRSF UART |
| STM32 UART | USART6 RX, PC7 |
| UART 설정 | 420000 baud, 8-N-1 |
| 제어 주기 | 5 ms, 200 Hz |

USART6 TX인 PC6은 현재 조종기 수신에 필요하지 않다. 자세한 STM32 설정은 [STM32F446RE 설정 정리본](../../STM32/STM32F446RE%20설정%20정리본.md#10-usart6--radiomaster-pocket-elrs--elrs-nano-수신기)을 따른다.

## 2. CRSF 채널 배치

EdgeTX 전용 모델의 `Mixes`를 다음과 같이 설정한다. 수신기가 채널 기능을 고정하는 것이 아니므로 새 모델을 만들거나 설정을 복사한 뒤에는 반드시 조종기 채널 모니터에서 순서를 다시 확인한다.

| CRSF 채널 | EdgeTX Source | Pocket 입력 | 제어기 입력 |
|---:|---|---|---|
| CH1 | Ail | 오른쪽 짐벌 좌우 | Roll |
| CH2 | Ele | 오른쪽 짐벌 상하 | Pitch |
| CH3 | Thr | 왼쪽 짐벌 상하 | Throttle |
| CH4 | Rud | 왼쪽 짐벌 좌우 | Yaw |
| CH5 | SA | 2단 스위치 | SA, `0/1` |
| CH6 | SB | 3단 스위치 | SB, `0/1/2` |
| CH7 | SC | 3단 스위치 | SC, `0/1/2` |
| CH8 | SD | 2단 스위치 | SD, `0/1` |
| CH9 | SE | 순간 버튼 | SE, `0/1` |
| CH10 | S1 | 가변 입력 | 조종 모드 보행 선택, 왼쪽 `0`·가운데 `2`·오른쪽 `1` |
| CH11~CH16 | - | - | 미사용 |

CH1~CH4는 `AETR` 순서이다. 물리 스위치의 위·가운데·아래 위치가 논리값 `0/1/2` 중 어느 값으로 들어오는지는 실제 조종기 시험에서 확인한다.

## 3. 입력값 규격

### 3.1 짐벌 값

CRSF에서 해석한 네 짐벌 채널은 STM32에서 다음 공통 형식으로 변환한다.

| 항목 | 값 |
|---|---:|
| 최소 | `-1000` |
| 중립 | `0` |
| 최대 | `1000` |
| 제어기 정규화 범위 | `-1.0~1.0` |

Throttle도 중립이 `0`인 양방향 값으로 사용한다. 따라서 별도 방향 스위치 없이 양수와 음수로 전진·후진 또는 상승·하강을 모두 명령한다.

현재 입력 전처리 초기값은 다음과 같다.

| 항목 | 현재 값 | 의미 |
|---|---:|---|
| Throttle Dead Zone | `±20 raw` | 중립 부근 스로틀 입력을 0으로 처리한다. |
| Yaw/Roll/Pitch Dead Zone | `±50 raw` | 중립 부근 짐벌 입력을 0으로 처리한다. |
| LPF Cutoff | `5 Hz` | Dead Zone 이후의 네 짐벌 입력을 평활화한다. |

Dead Zone 밖의 남은 범위는 다시 `-1.0~1.0`으로 선형 정규화한다. 실제 조종기가 준비되면 채널별 최소값·중립값·최대값·방향을 설정 테이블에 기록하고 위 값은 실측 결과에 맞춰 조정한다.

### 3.2 연속 입력 규칙

실제 짐벌처럼 명령이 시간에 따라 연속적으로 변하도록 한다. 임시 조종기 입력과 시험 입력은 raw 변화율을 `5000/s`로 제한한다.

| 변화 구간 | 소요 시간 |
|---|---:|
| `0 → ±1000` | `0.2 s` |
| `-1000 ↔ 1000` | `0.4 s` |
| 5 ms당 최대 변화량 | `25 raw` |

SA~SE는 디지털 입력이므로 Ramp 없이 즉시 전환한다. S1은 실측 최소·최대값 전체 범위를 세 구간으로 나누고 채널 방향 보정을 적용한다. `33.3%` 미만은 세 발 회전 보행, `33.3~66.6%`는 한 발 회전 보행, `66.6%` 초과는 세 발 횡이동 보행을 선택한다. 두 경계값은 가운데 구간에 포함한다. S1의 실측 중립값은 이 구간 폭을 바꾸지 않는다.

강화학습 모드는 SB 첫 위치에서 선택한다. 조종기는 Throttle의 전후 속도와 Yaw의 회전 속도만 전달하며, Roll·Pitch 짐벌과 S1 보행 선택은 사용하지 않는다. 정책은 몸체 절대 Roll·Pitch 목표와 다리별 기본 착지/높이 `(x, y, z, h)`의 잔차 `(dx, dy, dz, dh)`를 출력한다. 자세는 제어 주기마다 제한을 거쳐 추종하고, 다리 잔차는 경로 검증 후 다음 Swing 시작에 고정한다. [구현 범위와 내부 입력 API](../../STM32/SB_RL_GAIT_SPI_CHANGE_PLAN.md#13-통신을-제외한-구현-상태)를 따른다. Jetson SPI 패킷은 기존 v2 그대로이며 정책 출력의 실제 SPI 연결은 후속 작업이다.

### 3.3 입력 상태 초기화

조종 모드와 보정 모드처럼 짐벌의 의미가 달라지는 상태로 전환할 때는 새 명령을 계산하기 전에 네 짐벌 필터 상태를 모두 0으로 초기화한다. 조종 모드에서 S1이 다른 구간으로 넘어갈 때는 Yaw 필터 상태를 0으로 초기화하고 현재 Heading을 새 목표로 저장한다.

## 4. 스위치 기능

STM32 현재 구현의 스위치 기능은 다음과 같다.

| 스위치 | 기능 | 현재 동작 |
|---|---|---|
| SA | 매니퓰레이터 기능 입력 | 상태를 UART5 매니퓰레이터 패킷에 실어 보냄 |
| SB | 강화학습·서기·착지 요청 | `0`은 서기 완료 후 강화학습, `1`은 새 서기 및 기존 SC 선택 유지, `2`는 착지 요청으로 처리함 |
| SC | 조종·ARM·보정 선택 | SB `1`에서 `0`은 조종, `1`은 ARM, `2`는 보정이며 SB `0`에서는 강화학습이 우선함 |
| SD | Kill 요청 | `1`일 때 Kill을 요청함 |
| SE | 명령 없는 READY | `1`일 때 조종·보정 명령을 차단하고 READY로 처리함 |
| S1 | 조종 모드 보행 선택 | `<33.3%`는 `0`, `33.3~66.6%`는 `2`, `>66.6%`는 `1`로 처리함 |

조종 모드에서 S1이 왼쪽 구간이면 세 발씩 x축 이동과 Yaw 회전을 사용하고, 가운데 구간이면 한 발씩 x축 이동과 Yaw 회전을 사용한다. 오른쪽 구간이면 세 발씩 Heading 유지 x·y축 이동을 사용한다. S1은 보정 모드의 이동 방향을 선택하지 않는다. ARM 모드에서는 6족 본체 관절 목표를 유지하고 CRSF 연결·Motion Armed·ARM 상태와 조종값을 UART5로 200 Hz 전송한다. 기존 매니퓰레이터 패킷의 S1 비트는 오른쪽 횡이동 선택 여부만 전달한다. 자율주행 명령원 연결은 아직 구현하지 않았다.

## 5. 조종 모드

조종 모드에서는 로봇의 이동 속도와 몸체 자세를 명령한다. 좌표계는 `+X 전진`, `+Y 왼쪽`, `+Z 위쪽`을 사용한다.

| 입력 | S1 위치 | 명령 | 사용자 명령 최대값 |
|---|---|---|---:|
| Throttle | 공통 | x축 전진·후진 속도 | `±0.10 m/s` |
| Yaw | 왼쪽, `0` | 몸체 Yaw 각속도 | `±18 deg/s` |
| Yaw | 가운데, `2` | 한 발 보행의 몸체 Yaw 각속도 | `±18 deg/s` |
| Yaw | 오른쪽, `1` | y축 좌·우 이동 속도 | `±0.07 m/s` |
| Roll | 공통 | 몸체 Roll 목표각 | `±45 deg` |
| Pitch | 공통 | 몸체 Pitch 목표각 | `±45 deg` |

S1이 왼쪽의 `0` 또는 가운데의 `2`이면 Yaw 짐벌을 움직이는 동안 목표 Heading이 회전하고, 짐벌을 중립으로 놓으면 그 시점의 Heading을 유지한다. 가운데 구간의 Wave 보행은 한 번에 한 발만 들어 나머지 다섯 발로 지지한다. 표의 최대값은 보행 제어기에 전달하는 사용자 요청이며, 실제 Wave 보행은 다섯 지지 위상 동안 기존 보폭 범위를 유지하도록 선속도·각속도에 `0.2`를 적용한다. 따라서 감속 후 요청 상한은 전후 `±0.02 m/s`, 회전 `±3.6 deg/s`이며, 발 작업공간에 따라 더 줄어든다. 최초 여섯 발 순회에서는 지지발 이동량을 한 번 더 절반으로 줄인다. S1이 어느 방향으로 바뀌든 전환 시점의 현재 Yaw를 새 목표 Heading으로 잡는다.

S1이 오른쪽의 `1`이면 Yaw 짐벌은 회전이 아니라 y축 이동을 명령한다. 사용자 Yaw 각속도는 0으로 두고 전환 시점의 Heading을 유지한다.

현재 `ROBOT_GAIT_YAW_FEEDBACK_ENABLE=0`이므로 Heading 자동 오차 보정은 꺼져 있다. 오른쪽 구간에서는 회전 명령과 Heading 목표를 고정하지만, 실제 지면에서 발생하는 방향 오차를 IMU로 자동 복구하지는 않는다.

Roll·Pitch의 사용자 입력 범위는 `±45 deg`이지만 실제 적용 명령은 현재 발 위치의 IK 작업공간을 넘지 않도록 제한된다. 여러 자세축이 동시에 입력되면 결합된 명령 전체를 적용할 수 있을 때만 갱신하고, 불가능하면 직전 유효 명령을 유지한다.

보행은 다음 중 하나가 충족될 때 시작된다.

| 조건 | 시작 임계값 |
|---|---:|
| x축 속도 절댓값 | `0.005 m/s` 이상 |
| y축 속도 절댓값 | `0.005 m/s` 이상 |
| Yaw 각속도 절댓값 | `1 deg/s` 이상 |

첫 보행 입력을 받은 뒤 `100 ms` 동안 입력이 안정될 시간을 둔다. Tripod는 한 명령을 두 걸음에 공통 적용하고 두 걸음의 착지 후 정지한다. Wave는 한 발이 착지할 때마다 다음 명령과 경로를 검사하며, 중립 입력에서는 현재 발의 착지 후 정지한다. Tripod와 Wave 사이의 전환도 현재 Swing이 끝나고 여섯 발 접촉이 확인된 뒤 새 경로 검사를 거쳐 적용한다.

## 6. 보정 모드

보정 모드는 로봇이 걷지 않는 상태에서 몸체 위치와 Yaw 자세를 미세 조정한다. 이 모드에서는 Tripod 보행을 사용하지 않는다.

| 입력 | 명령 | 최대값 |
|---|---|---:|
| Pitch | 몸체 x축 이동 속도 | `±0.10 m/s` |
| Roll | 몸체 y축 이동 속도 | `±0.07 m/s` |
| Throttle | 몸체 z축 이동 속도 | `±0.10 m/s` |
| Yaw | 몸체 Yaw 보정 목표각 | `±30 deg` |

Yaw는 각속도가 아니라 짐벌 위치에 직접 대응하는 목표각이다. Yaw 짐벌을 중립으로 놓으면 보정 목표각도 `0 deg`로 복귀한다. x·y·z 이동과 Yaw 자세 명령도 발의 IK 작업공간 안에서만 갱신하며, 적용할 수 없는 명령은 직전 유효 명령을 유지한다.

## 7. 암 모드

SC가 `1`이면 ARM 모드에 진입한다. STM32는 6족 본체의 직전 18개 관절 명령을 유지하고, 다음 입력을 정규화된 `-1000~1000` 값으로 UART5 패킷에 실어 매니퓰레이터로 전달한다. 말단 속도 범위와 작업공간 제한은 매니퓰레이터 수신 제어기에서 정한다.

| 입력 | 명령 |
|---|---|
| Throttle | 매니퓰레이터 말단의 z축 이동 속도 |
| Yaw | 매니퓰레이터 손목의 회전 속도 |
| Roll | 매니퓰레이터 말단의 y축 이동 속도 |
| Pitch | 매니퓰레이터 말단의 x축 이동 속도 |
| SA | 그리퍼 열림·닫힘 |

패킷은 16바이트, 115200 baud, 200 Hz이며 상세 형식은 [매니퓰레이터 유선 UART 패킷 명세](../../STM32/Manipulator_UART_Protocol.md)를 따른다. 수신 측은 CRSF 연결, Motion Armed와 ARM Mode Flag가 모두 1일 때만 명령을 적용한다. SE의 `1` 상태는 ARM보다 우선하여 짐벌 명령을 차단하고 READY로 복귀시킨다.

## 8. 자율주행 모드

SB의 한 위치는 최종적으로 자율주행 명령원을 선택하는 데 사용한다. 자율주행 모드에서도 SD Kill은 항상 사용할 수 있어야 한다. 자율주행 명령의 종류와 조종기 수동 개입 방식은 자율주행 제어를 구현할 때 확정한다.

현재 STM32에는 Jetson `COMMAND` 프레임의 검증·보관 API까지 구현되어 있지만 이를 보행 명령원에 연결하지 않았다. 현재 SB는 `0`에서 상태를 유지하고, `1`에서 새 서기를 요청하며, `2`에서 착지를 요청한다.

## 9. 동작 허가와 통신 끊김

서기 또는 착지 중에는 짐벌 명령을 로봇 동작으로 전달하지 않는다. 서기가 끝나 READY 상태가 된 뒤 네 짐벌이 다음 중립 범위에 연속 `0.2 s` 동안 있어야 이동과 보정 명령을 허용한다.

| 입력 | 중립 판정 범위 |
|---|---:|
| Throttle | `±20 raw` |
| Yaw/Roll/Pitch | `±50 raw` |

마지막 정상 CRSF 프레임을 받은 뒤 `100 ms`가 지나면 연결 끊김으로 판단한다. STM32에서는 이때 모든 사용자 이동 명령을 0으로 만들고 보행 및 동작 허가를 해제하여 현재 STANCE 위치를 유지한다. 연결이 복구되어도 네 짐벌이 다시 `0.2 s` 동안 중립을 유지한 뒤에만 동작을 허가한다. 이 처리는 Safety Fault가 아니라 조종 입력 Failsafe이다.

## 10. 실기 보정 항목

실제 조종기와 수신기가 준비되면 다음 항목을 채널별 설정 테이블에 기록한다.

- CRSF 최소·중립·최대 raw 값
- 짐벌 축별 방향 반전 여부
- 스위치 물리 위치와 논리값 `0/1/2`의 대응
- 중립 떨림을 고려한 Dead Zone
- 조종 감각을 고려한 LPF Cutoff와 최대 명령값

보정 전에는 이상적인 `-1000~1000` 입력을 가정한다. 보정 후에도 제어기로 전달하는 최종 형식은 중립 `0`, 범위 `-1000~1000`으로 유지한다.

## 11. 입력 시험 순서

조종기가 없을 때는 임시 입력 생성기로 먼저 시험하고, 이후 저장된 CRSF 프레임과 실제 수신기로 범위를 넓힌다. 짐벌 이동 시험에는 `+1000` 또는 `-1000`을 사용하고 S1 선택 시험에는 세 구간의 내부값과 `33.3%`, `66.6%` 경계의 앞뒤 값을 사용한다. 각 짐벌 명령을 중립 `0`으로 복귀시키고 해당 동작의 정지 또는 자세 안정이 끝난 뒤에만 다음 시험으로 넘어간다.

보행 최대 명령은 시작 확인 `0.1 s`와 전체 보행 주기를 포함해 충분히 유지하고, 완전 착지와 정지를 확인한 뒤 다음 입력을 준다. 기본 위상 `1.0 s` 기준 Tripod는 `2.0 s`, Wave는 `6.0 s`가 한 주기이며 접촉 대기 중에는 더 길어진다. 몸체 자세와 보정 명령은 각 방향으로 `1.0 s` 동안 입력하고 반대 방향 시험 전에 `2.0 s` 동안 중립을 유지한다. 여러 이동축의 개별 최대값은 각각 시험하며, 작업공간을 넘는 합성 최대 속도를 만들기 위해 모든 축을 동시에 최대값으로 고정하지 않는다.

1. 네 짐벌이 중립에서 `0`이고 양 끝에서 `-1000/1000`이 되는지 확인한다.
2. 모든 짐벌 Ramp가 중립→최대 `0.2 s`, 최소↔최대 `0.4 s`인지 확인한다.
3. SB `0`에서 상태 유지, `1`에서 서기·READY, `2`에서 착지 전환을 확인한다.
4. SC `0`의 조종, `1`의 상태 유지, `2`의 보정 선택과 SE의 READY 전환을 확인한다.
5. S1을 `33.3%` 미만의 `0`에 두고 세 발 보행의 Throttle 양·음 전진·후진과 Yaw 양·음 회전을 확인한다.
6. S1을 `66.6%` 초과의 `1`에 두고 Throttle과 Yaw를 각각 `±1000`으로 입력하여 세 발씩 x·y 양방향 이동하고 사용자 회전 명령이 0인지 확인한다.
7. S1을 `33.3~66.6%`의 `2`에 두고 한 번에 한 발만 들며 전진·후진과 양방향 회전하는지 확인한다. 두 경계값도 가운데 선택에 포함되는지 확인한다.
8. 조종 모드와 보정 모드 전환 순간에 네 짐벌의 이전 명령이 남지 않는지 확인한다.
9. 보정 모드의 x·y·z 양방향 이동과 Yaw `±30 deg` 명령을 확인한다.
10. CRSF가 `100 ms` 끊겼을 때 명령이 0이 되고, 재연결 후 중립 `0.2 s` 전에는 다시 움직이지 않는지 확인한다.
11. SD Kill이 지정된 스위치에서만 동작하고 SC 가운데가 Reset을 발생시키지 않는지 확인한다.
12. SC `1`의 ARM 모드에서 본체가 자세를 유지하고 UART5로 짐벌 네 축과 SA 상태가 전송되는지 확인한다.
13. 자율주행 구현 후 SB 전환과 SD Kill 우선 동작을 확인한다.
14. S1의 세 구간을 서로 전환할 때 Yaw 필터가 초기화되고, 보행 종류는 현재 Swing과 여섯 발 접촉 확인을 완료한 뒤 바뀌는지 확인한다.

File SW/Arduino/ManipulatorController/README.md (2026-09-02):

# Arduino Uno 매니퓰레이터 제어기

`드론 조종기 입력/README.md`와 `Manipulator_UART_Protocol.md`를 기준으로 Arduino Uno에서 6개 PWM 서보를 제어한다. STM32 소스는 수정하지 않는다.

## 부팅 동작

부팅 자세 정렬은 통신 및 ARM 모드와 무관하게 한 번 실행한다.

1. Uno가 J1~J6을 `D5~D10`에서 0.25초 간격으로 활성화한다.
2. 정상적인 직전 종료 자세인 접힌 초기포즈 펄스에서 시작한다.
3. 직립 영점까지 `2us/20ms`로 천천히 이동한다. 최대 이동 관절 기준 약 7.4초다.
4. 직립 영점에서 2초 동안 토크를 유지한다.
5. 접힌 초기포즈까지 `5us/20ms`로 이동한다. 최대 이동 관절 기준 약 3초다.
6. 초기포즈를 토크로 유지하면서 ARM 조종 허가를 기다린다.

일반 3선 PWM 서보에는 현재각 피드백이 없다. 코드가 전원 인가 당시의 임의 자세를 자동 측정할 수는 없다. 부팅 시 같은 Uno의 EEPROM에서 J1~J6 영점값을 읽고, 그 영점과 `READY_DEG[]`로 접힌 초기포즈 펄스를 계산한다. 전원이 꺼진 동안 팔을 손으로 옮긴 경우 첫 PWM 명령에서 움직임이 발생할 수 있다. 임의 자세에서도 항상 저속 이동하려면 관절 엔코더, 별도 위치 피드백 또는 피드백 지원 서보가 필요하다.

## UART 연결과 패킷

- STM32 `UART5_TX/PC12` → Uno `D0/RX`
- STM32 GND와 Uno GND 공통
- `115200 baud, 8-N-1`, STM32→Uno 단방향
- 고정 16바이트, little-endian
- Sync `A5 5A`, Version `01`
- CRC-16/CCITT-FALSE: poly `0x1021`, init `0xFFFF`, xorout `0`
- CRC 입력: Byte 0~13, CRC 저장: Byte 14 Low, Byte 15 High

| Byte | 필드 |
|---:|---|
| 0 | `0xA5` |
| 1 | `0x5A` |
| 2 | Version `0x01` |
| 3 | Sequence |
| 4 | Flags |
| 5 | Switches |
| 6~7 | Roll `int16_t` |
| 8~9 | Pitch `int16_t` |
| 10~11 | Throttle `int16_t` |
| 12~13 | Yaw `int16_t` |
| 14~15 | CRC16 little-endian |

수신기는 Sync 검색, Version 검사, CRC 검사, Sequence 중복 검사를 수행한다. 손상된 프레임은 한 바이트씩 재동기화하며 정상 프레임만 명령 상태를 갱신한다.

## ARM 조종 조건

부팅 자세 정렬이 끝난 뒤 다음 조건이 모두 만족될 때만 조종값을 적용한다.

- Bit 0: Controller connected
- Bit 1: Motion armed
- Bit 2: STM32 ARM mode allowed
- Switches의 `SC == 1`: ARM mode

매핑은 다음과 같다.

- Roll: 말단 y축 이동
- Pitch: 말단 x축 이동
- Throttle: 평상시 말단 z축 이동, SA를 누르는 동안 그리퍼 비례 개폐
- Yaw: 손목 회전
- SA: Throttle의 그리퍼 제어 모드 선택

짐벌에는 ±35의 데드밴드와 약 0.1초의 저역통과 필터를 적용한다. Pitch·Throttle 입력은 J2·J3 역기구학으로 x·z 방향 속도로 변환하고 J4를 함께 보정하여 말단 피치를 유지한다. 최대 x·z 속도는 `90mm/s`, 베이스 방향 속도는 `70mm/s`, 손목 회전은 `50deg/s`이며 실제 출력은 관절별 PWM slew limit로 한 번 더 제한한다.

ARM 해제, 연결 해제, Motion armed 해제, CRC/Version 오류, 중복 Sequence 또는 정상 패킷 100ms timeout에서는 원점 복귀나 PWM detach를 하지 않고 마지막 관절 목표를 계속 유지한다.

ARM 모드는 SC 값으로 판정한다. SA를 누른 동안 Throttle 최저는 그리퍼 열림, 최고는 닫힘으로 비례 매핑되고 z축 이동은 정지한다. SA를 놓으면 마지막 그리퍼 각도를 유지하면서 Throttle이 다시 z축 이동을 제어한다.

## 시리얼 디버그

USB 시리얼 모니터를 `115200 baud`로 열면 0.5초마다 `DBG` 한 줄을 출력한다. `bytes`는 D0에서 읽은 바이트 수, `ok`는 정상 패킷 수, `verErr`와 `crcErr`는 형식 오류 수, `ageMs`는 마지막 정상 패킷 이후 시간이다. `SC=1`, `safety=1`, `arm=1`, `allow=1`이어야 조종 입력이 적용된다. 시리얼 모니터를 열면 Uno가 리셋되어 부팅 자세 정렬부터 다시 실행될 수 있다.

## 실기 보정값

코드 상단 `Config`에서 다음을 실측해야 한다.

1. 기본 `HOME_US[]`는 실측값 `{1290,1600,1480,1510,1610,1540}`이다.
2. `ManipulatorCalibration.ino`를 끝까지 실행하면 J1~J6 값이 EEPROM에 저장되고, 이후 제어기는 여섯 값을 모두 자동 적용한다. 보정이 중단되었거나 저장값이 유효하지 않으면 위 기본값을 사용한다.
3. 부팅 접힌 자세 펄스는 `HOME_US[]`, `READY_DEG[]`, 방향과 서보 각도당 펄스로 계산한다.
4. `SERVO_DIRECTION[]`: 현재 J3(D7)만 `-1`로 반전했다.
5. `READY_DEG[]`: 현재 `{0, +35, -100, -25, 0, 0}` 근사값이다.
6. `LINK1_MM`, `LINK2_MM`: 어깨-팔꿈치와 팔꿈치-손목 축간거리로 교체한다.
7. `JOINT_MIN_DEG[]`, `JOINT_MAX_DEG[]`: 실제 기구 충돌 한계로 좁힌다.

## 캘리브레이션 순서

1. STM32 TX선을 Uno D0에서 분리한다.
2. `../ManipulatorCalibration/ManipulatorCalibration.ino`를 Uno에 업로드한다.
3. 시리얼 모니터를 `115200 baud`, 줄바꿈으로 열고 J1(D5)부터 J6(D10)까지 `up`, `down`, `ok`로 맞춘다.
4. 마지막 J6에서 `ok`를 입력해 `HOME_US={...}`가 출력되어야 전체 EEPROM 기록이 유효해진다.
5. `ManipulatorController.ino`를 다시 업로드하고 부팅 때 출력되는 `HOME_US={...}`가 같은지 확인한다.

첫 통합 시험은 팔을 받침대로 지지하고 한 축씩 전원을 연결한다. 반대 방향, 드드드 진동, 링크 비틀림, 전압 강하 또는 발열이 보이면 즉시 서보 전원을 끈다.

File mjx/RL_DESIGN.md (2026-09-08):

# STM32 펌웨어 기반 지형 curriculum residual 강화학습

## 기준 제어기

학습 환경의 base controller는 `tripod_controller.py`의 독립 Python 보행기가
아니다. 실제 STM32 모듈을 호출하는 `native/firmware_controller_bridge.c`와 같은
순서·상태·상수를 `firmware_mjx_controller.py`에 JAX로 옮긴 것이다.

```text
목표 vx/wz
  → 5 Hz command LPF
  → Position/Heading feedback + rate limit
  → gait workspace preview
  → contact-gated Tripod / Early·Late Landing
  → PULL/Bezier foot trajectory
  → roll/pitch posture feedback
  → bounded RL foot residual + phase-gated adaptive swing height
  → workspace gate / IK hold / 315.8 deg/s joint limit
  → MuJoCo DS51150 position actuators (12.6 V, ±14.709975 Nm stall)
```

한 RL step은 20 ms이며 내부에서 펌웨어 주기 5 ms를 네 번 실행한다. 발 접촉은
높이 proxy가 아니라 MuJoCo의 `foot_collision`–world collision pair만 사용한다.

## 로봇 질량과 DS51150 서보 모델

RL용 `mjx/generated/hexapod_rl.xml`을 만들 때 원본 CAD 링크의 질량과 관성을 같은
비율로 스케일해 로봇 전체 질량을 정확히 `10.0 kg`으로 맞춘다. 이 값은 현재 학습
plant의 목표 질량이며, 완성된 실물 로봇의 실측 질량을 의미하지 않는다.

| 항목 | 값 | 근거 |
|---|---:|---|
| supply | 12.6 V | DS51150-270 고전압 사양 |
| gear ratio | 357:1 | 제조사 사양 |
| stall torque | 150 kgf·cm = 14.709975 Nm | 제조사 사양, actuator hard cap |
| no-load speed | 0.19 s/60° = 315.8 deg/s | 제조사 사양, 목표각 rate limit |
| position gain | `kp=500`, `kv=10` | calibration prior |
| output armature | `0.02 kg·m²` | calibration prior |
| joint damping | `0.15 Nms/rad` | calibration prior |
| gear friction loss | `0.8 Nm` | calibration prior |

기어 출력의 armature, damping, dry friction을 joint에 포함해 토크 포화 시 관절이
무마찰 자유 힌지처럼 퍼지는 기존 모델을 방지한다. 단, 마지막 네 값은 제조사
데이터가 아니므로 실기에서 무부하 전류·step response·외력 backdrive를 측정한 뒤
`servo_model.py`만 수정해 재식별해야 한다. 학습 metadata에도 이 전체 계약을 남긴다.

`test_servo_model.py`는 생성 scene의 10 kg 질량, 18개 actuator의 gain/force range,
joint armature/damping/friction과 5초 powered-home 자세 유지를 회귀 검사한다.

## Action 18-D

다리 순서는 펌웨어와 같은 `RF, RM, RB, LF, LM, LB`이다.

| 범위 | 의미 | 한계 |
|---|---|---|
| `0:18` | 다리별 local XYZ action | Swing X/Y ±100 mm; Z는 높이 4~25 cm |

- Swing X/Y는 Cartesian residual로 적용한다.
- Swing Z는 `-1/0/+1 → 4/6/25 cm` 높이 명령이며, phase envelope를 곱해
  이륙점과 착지점의 Z offset은 항상 0이다.
- Stance Z는 ±100 mm까지 요청할 수 있고 XY는 0이다. 최종 workspace/IK gate는 그대로다.
- Late-Landing에는 RL residual을 적용하지 않고 펌웨어 하강 탐색만 사용한다.
- residual은 0.10초 low-pass filter를 지난다.
- IK 2-link 작업공간은 경계 안쪽 1 mm에서 제한한다.
- 도달 불가능한 residual은 다리별로 거부되고 펌웨어 nominal 목표를 사용한다.
- 정책은 범위 내 swing X/Y·높이 및 stance Z residual을 선택할 수 있다. gait
  phase/frequency, radial offset 0.07 m, contact state machine, 자세 PI, IK 또는
  관절 속도 제한은 바꿀 수 없다.

계약 이름은 `stm32_firmware_adaptive_swing_residual_100mm_v4`이다. tensor 크기는 계속
18-D지만 v2의 Z는 Cartesian endpoint offset이고 v3의 Z는 phase-gated 높이 명령이라
의미가 다르다. v4는 v3보다 XY/stance Z scale이 커졌다. 따라서 v1/v2/v3 및 과거 22-D checkpoint는 현재 v4로 직접 복원하지 않는다.

## Observation 146-D

현재 계약은 `firmware_state_collision_terrain_command5_pitch_v3`이다.

| slice | 내용 |
|---|---|
| `0:5` | 전진·yaw·height·pitch·roll command |
| `5:16` | 몸체 속도·각속도·중력·상대 roll/pitch |
| `16:52` | 18개 관절 위치·속도 |
| `52:76` | 발 controller-body 위치·collision contact |
| `76:91` | heading 기준 지형 높이 15개 |
| `91:103` | gait progress/state |
| `103:107` | 적용 twist |
| `107:127` | IK valid·policy valid·projection·gait/posture acceptance |
| `127:145` | 이전 action |
| `145:146` | pitch feedforward |

루트 학습 환경은 GT 지형을 쓰는 teacher/개발 경로다. LiDAR 입력 뷰어는 격리된 v3 소스에서
`76:91`을 센서 값으로 바꾸고 GT feedforward를 끈다. v4 학습과 stage31 v3 재생을 구분한다.
142-D 관측은 아래 이전 teacher 이관 설명의 레거시 계약이다.

## 제어기 발산 종료 조건

기존 환경은 약 69°까지 기울어져도 계속 진행했고 `termination=-2`에도 `dt`를
곱해 실제 페널티가 약 -0.04에 불과했다. 이제 다음 중 하나가 발생하면 즉시
failure로 종료하며 **시간 간격을 곱하지 않은 -30**을 준다.

- 펌웨어 최종 IK가 한 다리라도 invalid
- 펌웨어 관절 목표가 ±135° 한계의 1° 이내
- root 선속도 > 1.5 m/s 또는 각속도 > 6 rad/s
- 관절 속도 > 20 rad/s
- roll 또는 pitch > 45°
- 지형 기준 몸체 clearance < 0.14 m
- torso–world collision
- qpos/qvel/controller target에 NaN 또는 Inf

`gait_accepted`, `posture_accepted`, policy residual 거부 및 workspace projection은
그 전 단계의 연속 페널티로 기록한다. 이 신호만으로 바로 종료하지는 않아 정책이
자세를 회복할 기회를 남긴다.

`run_firmware_base.py`도 기본적으로 같은 controller-failure 조건에서 폭발 전에
멈춘다. 실패 장면을 끝까지 관찰해야 할 때만 `--allow-unsafe`를 붙인다.

## 지형 curriculum

| Level | 지형 | 상세 |
|---:|---|---|
| 0 | 평지 | 최소 baseline 후 competence 미달 시 한 번 더 시도 |
| 1 | 울퉁불퉁 | 최대 2.5 cm 높이 타일 |
| 2 | 강한 울퉁불퉁 | 최대 5 cm 높이 타일 |
| 3 | 경사면 | 8° 연속 경사 |
| 4 | 가파른 경사면 | 15° 연속 경사 |
| 5~10 | 7단 계단 | 한 riser 5/6.5/8/10/15/20 cm |
| 11~16 | 연속 10단 계단 | 한 riser 5/6.5/8/10/15/20 cm |

최종 level 16은 **20 cm riser가 10번 연속**되며 최상단은 바닥에서 2 m다.
Level 0은 기본 262,144 step(기본 PPO 설정의 4 update) baseline으로 시작하고,
competence 미달이면 한 번 더 시도한다. Level 0~3(평지, 두 rough, 8° 경사)은
level당 최대 2회, Level 4~16(15° 경사부터 최종 계단)는 최대 4회 시도한다.
각 stage의 `eval/episode_terrain_success`가 기본 0.80 이상이면 제한에 닿기 전에도
즉시 다음 level로 올라간다. `--max-stages-per-level N`을 명시하면 이 2/4 규칙을
전체 level 공통 N회로 override한다. stage 사이에 최고 평가 checkpoint를
이어가려면 `--checkpoint-selection best`를 사용한다.

## 보상과 성공

- 자동 ramp/계단 curriculum의 pitch command는 0이고, 전방 0.40/0.65/0.90 m
  지형 높이로 계산한 `pitch_ff`만 지형 자세 목표로 사용한다. 명시적 pitch command는
  외부 명령을 위한 additive offset으로 남겨 두며, 자동 curriculum에서 같은 경사를
  `pitch_cmd + pitch_ff`로 두 번 더하지 않는다.
- 0.5초 EMA 전진속도를 `0.04 m/s` 폭으로 엄격하게 목표 속도에 추종시키고,
  `vx / vcmd`로 정규화한 전진 progress를 직접 보상한다. 목표 미달 속도는 별도
  제곱 페널티를 받는다.
- upright, 지형 기준 몸체 높이, 낮은 각속도와 관절 여유 같은 양의 보조 보상은
  전진속도 gate를 통과한 만큼만 지급한다. 따라서 제자리 보행은 생존 보상을
  누적할 수 없다.
- command 활성화 후 3초 동안 `root_x + 0.5 * support_height`가 2 cm 이상
  증가하지 않으면 no-progress 실패로 종료하고 시간 간격을 곱하지 않은 -10을 준다.
- 관절 한계 근접 보상 가중치를 높이고 policy residual 거부와 workspace projection은
  각각 더 강하게 감점해, 제한에 걸리는 동작보다 작은 안전 residual을 우선 학습한다.
- torque/saturation, joint velocity, lateral/vertical velocity, residual 크기와 변화,
  controller/policy rejection, body/self collision을 페널티로 둔다.
- Swing 높이 자체와 공중에 뜬 뒤 Swing 전반부에 다시 충돌하는 toe scuff를 별도
  페널티로 둬, 평지에서는 낮게 들고 장애물 통과에 필요한 경우에만 높이를 사용한다.
- 경사면/계단에서 새 최고 높이에 처음 도달할 때만 ascent bonus를 지급해 접촉 높이 떨림으로
  보상을 반복 획득할 수 없게 한다.
- 지형 끝을 몸체가 통과하고 경사면/계단의 최종 높이 지지가 확인되며 roll/pitch가 20°
  이내이면 success 종료와 +30 보너스를 준다.
- episode는 평지 20초, rough/ramp/7단 계단은 50초, 연속 10단 계단은 100초가 기본이다.

## 실행

```bash
cd /home/huro/Hexapod-Robot
PY=/home/huro/.venvs/hexapod-mjx/bin/python

# 환경/계약만 검증
$PY mjx/train_rough_terrain.py --terrain-level 1 --smoke
$PY mjx/train_rough_terrain.py --terrain-level 4 --smoke
$PY mjx/train_rough_terrain.py --terrain-level 16 --smoke

# 한 난이도만 직접 학습
$PY mjx/train_rough_terrain.py \
  --run-name firmware-final-stairs \
  --terrain-level 16 \
  --timesteps 50000000 --num-envs 2048 \
  --num-evals 10 --num-eval-envs 32 \
  --wandb --wandb-project hexapod-firmware-terrain
```

실제 학습은 GPU JAX backend를 요구한다. `--allow-cpu`는 아주 작은 디버깅에만
사용한다. 모든 level에서 action/observation tensor 계약은 같아 checkpoint를
안전하게 이어받는다.

원래 사용하던 competence launcher 형태로 평지 baseline부터 전체 계단까지 돌리는
권장 명령은 다음과 같다.

```bash
$PY mjx/train_competence_curriculum.py \
  --run-name firmware-terrain-final-stairs \
  --flat-baseline-timesteps 262144 \
  --stages 44 --stage-timesteps 5000000 \
  --start-level 1 --max-level 16 \
  --level-progression competence \
  --wandb --wandb-project hexapod-firmware-terrain \
  -- --num-envs 2048 --num-evals 10 --num-eval-envs 32
```

`num-envs`는 총 sample 수가 아니라 병렬 rollout 폭이다. 기본 PPO 설정에서는
2048이 한 번의 rollout batch이고, 1024로 낮추면 같은 65,536 sample을 두 번에
나누어 계산하므로 학습량이 절반이 되지 않는다. rough terrain은 32개 box 대신
단일 heightfield collision을 사용해 MJX contact graph 크기를 제한한다. 동일 shape의
재시작은 기본적으로 `~/.cache/hexapod-mjx/jax`의 persistent XLA cache를 재사용한다.
기본 `--collision-mode lower_leg`는 계단에 필요한 foot/tibia/torso 접촉을 유지하되
제한된 residual 정책에서 불필요하게 큰 링크 간 self-collision graph는 만들지 않는다.
전체 링크와 self-collision이 필요한 검증 run에서만 `--collision-mode full`을 쓴다.
순수 throughput 확인에서는 `--no-eval --no-stage-video`를 사용하면 학습 뒤의 긴
episode evaluation과 렌더링을 건너뛸 수 있다. Curriculum 실행에는 평가 결과가
필요하므로 `--no-eval`을 전달하면 안 된다.

`competence`는 `eval/episode_terrain_success`가 0.80 이상이면 level을 올리고,
미달하면 같은 level을 반복한다. 매 stage를 무조건 올리려면
`--level-progression sequential`을 쓴다. 기존 checkpoint에서 시작할 때는 launcher에
`--init-checkpoint mjx/runs/terrain/<run>/checkpoints`를 지정한다. 로더는 18-D,
146-D, network layer 및 action/observation semantic contract가 모두 맞을 때만 승계를 허용한다.
이전 run의 stage 번호까지 이어 표시하려면 다음 stage 번호를 `--start-stage`로
지정한다. 첫 stage는 기본적으로 actor만 복원하고 critic은 새 지형에서 다시 학습한다.

현재 v4는 residual scale이 바뀌므로 기존 v3 actor를 직접 이어받지 않고 새 run을 시작한다.

```bash
/home/huro/bin/hexapod-mjx-python mjx/train_competence_curriculum.py \
  --run-name firmware-terrain-adaptive-swing \
  --seed 8 --flat-baseline-timesteps 262144 \
  --start-level 1 --max-level 16 \
  --stages 44 --stage-timesteps 5000000 \
  --level-progression competence \
  --checkpoint-selection best \
  --wandb --wandb-project hexapod-firmware-terrain \
  -- --num-envs 1024 --num-evals 4 --num-eval-envs 32
```

### Teacher-student 보행 보존 학습 — 이전 v3 이관 기록

아래는 142-D→146-D 및 v2/v3 teacher 이관 경로의 기록이다. 현재 v4에 이전 가중치를 바로 적용하는
명령으로 해석하지 않는다. v4와 호환되는 teacher/변환 계약을 마련해야 한다. LiDAR sensor student와
GT supervision의 후속 구조는 [최신 설계](../docs/HEXAPOD_LIDAR_FOOTHOLD_RESIDUAL_PLAN.md)를 따른다.

Command5/posture 조건을 유지하면서 기존 142-D 보행을 보존할 때는 frozen teacher
manifest를 launcher에 전달한다. Adaptive-swing v3 teacher는 18-D 전체 action을,
Cartesian v2 teacher는 의미가 호환되는 다리별 X/Y 12개 action만 지도한다. 현재
146-D observation은 `[0:2] + [5:145]`로 legacy 142-D teacher observation에
투영하며, teacher checkpoint를 일반 `--init-checkpoint` gate로 복원하지 않는다.

```bash
/home/huro/bin/hexapod-mjx-python mjx/train_competence_curriculum.py \
  --run-name firmware-terrain-command5-teacher-student-v1 \
  --run-root /home/huro/Hexapod-Robot/mjx/runs \
  --seed 8 \
  --flat-baseline-timesteps 262144 \
  --start-level 1 --max-level 16 \
  --stages 44 --stage-timesteps 5000000 \
  --level-progression competence --promote-threshold 0.80 \
  --checkpoint-selection best \
  --teacher-manifest mjx/teacher_manifests/walking-teachers-v1.json \
  --teacher-huber-delta 0.10 \
  --wandb --wandb-project hexapod-firmware-terrain \
  -- --num-envs 2048 --num-evals 4 --num-eval-envs 32 \
     --dr-bank-size 16 --collision-mode lower_leg \
     --best-video --no-stage-video --no-progress-video
```

Fresh curriculum의 actor/normalizer는 level-0 v3 teacher의 142-D 입력 layer를
146-D로 확장해 시작한다. 새 height/pitch/roll/pitch-FF 입력 weight는 0이고 critic은
현재 reward에 맞춰 새로 시작한다. 이후 stage는 current student checkpoint를 정상
승계하면서 level별 teacher loss만 바뀐다. `best` pointer는 manifest 사용 시 기본
best-safe 제한(policy rejection 1%, foot-limited 1%, failure 5%)을 통과한 평가만
가리킨다. 모든 teacher 경로와 weight는 각 run의 `run_metadata.json` 및 curriculum
history에 기록된다.

## W&B, checkpoint, 영상 산출물

최초 한 번만 다음을 실행한다. `wandb`는 `requirements-train.txt`에 포함되어 있다.

```bash
$PY -m pip install -r mjx/requirements-train.txt
/home/huro/.venvs/hexapod-mjx/bin/wandb login
```

각 실행은 `mjx/runs/terrain/<name>_<timestamp>_seed<seed>/` 아래에 독립 저장된다.

- `checkpoints/`: 매 evaluation의 일반 Brax checkpoint
- `monitor/best_checkpoint.json`: NEW_BEST와 정확히 같은 `checkpoints/<step>` 경로
- `monitor/level_best_checkpoint.json`: safety gate와 무관한 현재 terrain level 최고 checkpoint
- `monitor/best_score.json`, `level_best_score.json`, `latest_metrics.json`, `metrics_history.jsonl`: 로컬 점수 기록
- `videos/best_levelY.gif`: 새 level-best 평가 직후 교체되는 해당 level 최고 영상
- `videos/stage_final_stageXX_levelY.gif`: `--stage-video`를 명시한 경우의 최종 정책 영상
- `videos/progress/`: `--progress-video`를 명시한 경우의 중간 정책 영상
- `run_metadata.json`: 펌웨어/action/observation/terrain/PPO/checkpoint 계약

W&B에서는 모든 stage가 launcher의 `--run-name` group 아래 별도 run으로 묶인다.
공통 x축은 `train/global_step`이다. 차트에는 reward/success, failure·safety rate,
진행·속도·자세 reward, teacher distillation 오차처럼 stage 판단에 필요한 핵심 metric만
기록하며 전체 metric은 로컬 `monitor/metrics_history.jsonl`에 보존한다. 새 level-best가
나오면 즉시 `level/best_video`와 `level/best_video_levelY`에 올리고, 같은 파일을
`policy-video` artifact로도 큐잉한다. `monitor/artifacts.jsonl`의
`wandb_queued=true`와 콘솔의 `wandb_best_video_queued`로 업로드 요청 여부를 확인한다.
네트워크가 없는
서버에서는 `--wandb --wandb-mode offline`으로 실행한 뒤 `wandb sync`를 사용한다.
offline 원본은 각 run directory의 `wandb/` 아래에 남는다.

기본 영상 정책은 각 evaluation의 새 level-best가 나올 때 동일한 level별 GIF를
원자적으로 교체하는 것이다. stage 종료 시에는 누락된 경우 한 번 더 생성한다.
stage-final, progress, teacher 영상은 기본적으로 꺼져 있으며 필요한 경우에만 각각
`--stage-video`, `--progress-video`, `--teacher-video`로 켠다. 영상은 각 20초다.
개수·길이는 `--progress-video-count`,
`--progress-video-duration`, `--best-video-duration`, `--stage-video-duration`으로
조절하며 `--no-stage-video`로 최종 영상도 끌 수 있다.

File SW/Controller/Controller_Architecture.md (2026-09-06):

# 6족 로봇 보행 제어기 Architecture

STM32 최종 펌웨어에 구현된 6족 로봇의 수동 조종, 자세·위치 피드백, Tripod 보행, 접촉 적응, 기구학과 Safety의 전체 구조를 정의한다. 세부 수식은 [Controller_detail.md](Controller_detail.md), 입력 채널은 [드론 조종기 입력 README](드론%20조종기%20입력/README.md), 좌표 부호는 [좌표축 README](좌표축/README.md)를 따른다. 값이 충돌하면 `SW/STM32/workspace/Hexapod/Core/Inc/common/robot_config.h`를 기준으로 한다.

## 1. 설계 기준

| 항목 | 현재 값 |
|---|---:|
| 제어 주기 | 5 ms, 200 Hz |
| 압력센서 주기 | 1 ms, 1 kHz |
| 기본 보행 | Tripod Gait |
| Tripod A | Leg 1, 3, 5 |
| Tripod B | Leg 2, 4, 6 |
| 한 Phase 시간 | 1.0 s |
| 최대 전진·후진 속도 | ±0.10 m/s |
| 최대 횡이동 속도 | ±0.07 m/s |
| 최대 Yaw 각속도 | ±18 deg/s |
| 최대 Roll·Pitch 목표각 | ±45 deg |
| 보정 모드 이동 속도 | x·z ±0.10 m/s, y ±0.07 m/s |
| 보정 모드 Yaw 목표각 | ±30 deg |
| 기본 Swing Height | 0.20 m |
| Swing Height 범위 | 0.05~0.25 m |
| Swing 방사 오프셋 | 0.07 m |
| IK 작업공간 여유 | 0.001 m |
| Late Landing 하강·안쪽 속도 | 0.12 m/s, 0.048 m/s |
| Late Landing 최대 탐색 | 0.10 m, 약 0.833 s |
| 관절 범위 | -135~135 deg |
| 서기 전 영점 정렬 속도 | 30 deg/s |

몸체 축은 +X 전진, +Y 왼쪽, +Z 위쪽을 사용한다.

## 2. 전체 제어 흐름

~~~text
센서와 사용자 명령
        ↓
상위 상태와 동작 허가 결정
        ↓
입력 정규화·Dead Zone·LPF
        ↓
적용 가능한 속도·자세 명령 결정
        ↓
몸체 위치 추정과 Position PI
        ↓
Heading PI와 몸체 자세 PI
        ↓
최종 Body Twist
        ↓
Tripod 위상과 Stance/Swing 궤적
        ↓
Early/Late Landing
        ↓
몸체 자세 오버레이
        ↓
다리 좌표 변환과 3DOF IK
        ↓
Safety와 관절 출력 제한
        ↓
18개 서보 PWM과 릴레이 출력
~~~

TIM6는 1 ms마다 압력센서 6채널 갱신을 요청하고, 다섯 번째 Tick마다 위의 전체 제어 흐름을 실행한다. GPS, LoRa와 같이 200 Hz가 필요하지 않은 통신은 실시간 제어 흐름과 분리한다.

## 3. 상위 상태와 모드

상위 상태는 다음 우선순위를 사용한다.

~~~text
KILL
  > ROLLOVER_FAULT
  > CONTROLLER_FAULT
  > LANDING
  > STANDING
  > READY
~~~

READY 안에서 조종 모드와 보정 모드를 실행한다. ARM 모드에서는 본체 관절 명령을 유지하고 조종기 상태를 UART5의 16바이트 패킷으로 매니퓰레이터에 200 Hz 전송한다. 자율주행 모드 자료형과 Jetson 명령 수신 저장소는 존재하지만, Jetson 명령을 보행 명령원에 연결하는 동작은 아직 구현하지 않았다.

| 상태 | 주요 동작 |
|---|---|
| LANDED | 착지 자세를 유지한다. |
| STANDING | 5.6 s 동안 기본 자세로 일어서고 0.5 s 안정 시간을 확인한다. |
| READY | 동작 명령을 받을 수 있는 서기 완료 상태이다. |
| MANUAL | 보행 속도와 Roll·Pitch 자세를 조종한다. |
| CORRECTION | 보행 없이 몸체 x·y·z 위치와 Yaw를 미세 조정한다. |
| ARM | 본체 자세를 유지하고 조종 명령을 매니퓰레이터로 전달한다. |
| LANDING | Swing 발을 정리한 뒤 5.6 s 동안 착지 자세로 내려간다. |
| FAULT | Safety Fault를 유지하고 서보 전원 릴레이를 끈다. |
| KILL | 사용자 Kill 요청에 따라 서보 전원 릴레이를 끈다. |

READY에 들어간 뒤 Throttle·Yaw·Roll·Pitch가 0.2 s 동안 중립이어야 동작을 허가한다. 서기·착지 중에는 짐벌 명령을 전달하지 않는다.

모드가 바뀌면 새 모드의 출력을 계산하기 전에 네 짐벌 필터 상태를 0으로 초기화한다. 조종 모드에서 S1이 중앙의 반대편으로 넘어가면 Yaw 회전 명령과 y축 이동 명령이 서로 이어지지 않도록 Yaw 필터만 초기화한다.

## 4. 사용자 명령

조종 모드의 주요 명령은 다음과 같다.

| 입력 | 명령 |
|---|---|
| Throttle | x축 전진·후진 속도 |
| Yaw, S1 왼쪽 | Yaw 회전 속도 |
| Yaw, S1 오른쪽 | Heading을 유지한 y축 좌·우 속도 |
| Roll | Roll 목표각 |
| Pitch | Pitch 목표각 |

보정 모드는 Pitch·Roll·Throttle로 몸체 x·y·z 이동 속도를 명령하고 Yaw로 상대 Yaw 목표각을 명령한다. 보정 Yaw는 각속도가 아니라 짐벌 위치에 직접 대응하며 중립에서 0 deg로 돌아온다.

실제 RC와 임시 시험 입력은 연속 조종 명령을 사용한다. SB 첫 위치의 강화학습 모드에서는 RC가 전후 속도·회전 속도만 지정하고, 정책이 몸체 절대 Roll·Pitch와 여섯 다리의 착지점·Swing 높이 잔차 `(dx, dy, dz, dh)`를 제공한다. STM32가 기본 경로와 잔차를 결합해 검증하고 다음 위상에 고정한 뒤 자세 제어·IK·PWM을 수행한다. 정책이 관절각을 직접 출력하지 않는다. [강화학습 구현 상태](../STM32/SB_RL_GAIT_SPI_CHANGE_PLAN.md#13-통신을-제외한-구현-상태)에 내부 입력 API를 정리했으며, Jetson SPI v2의 패킷 변경과 실제 수신 연결은 아직 수행하지 않았다.

## 5. 몸체 위치 추정

STANCE이면서 발 접촉이 확인된 다리만 위치 추정에 사용한다. 각 다리는 관절 측정각의 FK, Stance 시작 때 저장한 지면 Anchor와 IMU 자세를 이용해 절대좌표계의 몸체 위치 후보를 계산한다.

다리별 후보 중 다른 정상 후보가 0.05 m 안에 없는 고립 후보는 해당 주기부터 평균에서 제외한다. 이 상태가 5회 연속, 즉 25 ms 유지되면 Stance Foot Slip으로 Latch한다. 해당 다리가 STANCE 또는 CONTACT 조건을 벗어나면 Latch를 해제하고 다음 Stance에서 Anchor를 다시 만든다.

정상 후보는 압력 크기로 가중하지 않고 단순 평균한다. 추정 결과는 절대좌표계 x·y·z 위치와 유효 다리 수, 6비트 Slip Leg Mask이다. 현재 Slip Mask는 진단값이며 Safety Fault를 직접 발생시키지 않는다.

## 6. 위치와 자세 피드백

### 6.1 Position PI

조종 모드의 적용 x·y 속도를 현재 Heading으로 절대좌표계에 회전하고 적분하여 목표 위치를 만든다. FK 기반 몸체 위치 추정과의 오차를 x·y Position PI에 입력한다.

Position PI는 조종 모드에서만 사용한다. z 위치는 추정하지만 Position PI에는 사용하지 않는다. 보정 모드의 x·y·z 명령과 암 모드에는 Position PI를 적용하지 않는다.

조종 모드 진입 시 목표 위치를 현재 추정 위치에 맞추고 적분항을 초기화한다. 현재 STM32 구현은 필터를 통과한 사용자 x·y 속도로 위치 기준을 적분하며, 작업공간 채택 결과를 위치 기준에 되먹임하지 않는다. Position (K_I)는 현재 0이고 적분 상태에는 고정 범위 제한만 적용한다.

### 6.2 Heading PI

S1 왼쪽에서는 사용자 Yaw 각속도를 적분해 목표 Heading을 만들고, IMU Yaw와의 오차를 Heading PI로 보정한다. S1 오른쪽에서는 사용자 Yaw 각속도를 0으로 두고 전환 시점의 Heading을 유지한다.

S1 위치가 어느 방향으로 바뀌든 현재 IMU Yaw를 새 목표 Heading으로 사용하여 전환 순간의 회전 Jump를 막는다.

### 6.3 몸체 자세 PI

조종 모드 Roll·Pitch와 보정 모드 Yaw는 하나의 몸체 자세 PI를 사용한다. 자세 PI 출력은 보정 각속도이며 200 Hz로 적분해 몸체 자세 오버레이를 만든다. 별도의 내부 각속도 PI는 두지 않는다.

자세 오버레이는 Tripod 위상, 보폭과 Swing 착지점을 변경하지 않는다. 선택된 6개 발끝 목표를 몸체 원점 기준으로 역회전하여 몸체만 기울이거나 회전시킨다.

## 7. 최종 Body Twist

조종 모드의 보행 명령은 다음 세 성분을 합한다.

~~~text
사용자 x·y 속도와 Yaw 각속도
  + x·y Position PI 보정
  + Heading Yaw PI 보정
  = 최종 보행 Body Twist
~~~

Roll·Pitch 자세 PI와 보정 모드 Yaw 자세 PI는 보행 Body Twist에 합하지 않는다. 보정 모드의 x·y·z 속도는 PI 없이 몸체 이동 경로에 직접 사용한다.

최종 Body Twist에는 축별 크기 제한과 변화율 제한을 적용한다. Position과 Heading Reference는 필터를 통과한 사용자 속도·각속도로 갱신하고, 보행 작업공간 채택 결과는 별도 적용 명령으로 관리한다.

## 8. Tripod Gait

Tripod 그룹은 다음과 같다.

~~~text
Tripod A = Leg 1, 3, 5
Tripod B = Leg 2, 4, 6
~~~

두 그룹은 1.0 s마다 STANCE와 SWING을 교대한다. 실제 x·y 이동 또는 Yaw 회전 명령이 임계값을 넘고 100 ms 동안 유지될 때 보행을 시작한다. 한 번 채택한 사용자 속도는 두 Tripod 걸음에 공통으로 적용하여 좌우 보폭을 맞추고, Heading PI 보정은 걸음 중에도 최신값을 합한다.

보행 명령이 중립으로 돌아오면 현재 두 걸음 묶음을 마치고 Swing 다리를 착지시킨다. 착지 완료 시점의 6개 STANCE 발끝 목표를 그대로 유지하며, 발끝 목표를 0이나 기본 위치로 순간 변경하지 않는다. 지지발 접촉이 사라지면 위상 진행을 멈추고 해당 발만 Late Landing 방식으로 다시 지면을 탐색한다.

보정 모드에서는 6개 다리를 모두 STANCE로 유지한 채 몸체 위치와 자세만 변경한다.

## 9. 발끝 궤적

### 9.1 Stance

STANCE 발은 지면에 고정된 것처럼 보이도록 몸체 선속도와 각속도의 반대 방향으로 발끝 목표를 갱신한다.

\[
\dot p_i=-v_B-\omega_B\times p_i
\]

### 9.2 Swing

Swing 착지점은 다음 Stance 동안 예상되는 몸체 이동과 회전을 절반 선행 보상해 계산한다. x·y·z 보간에는 Cubic Smoothstep을 사용하고, 높이는 가운데에서 최대가 되는 포물선 항을 더한다.

Swing 중간에는 다리 장착 방향 바깥쪽으로 최대 0.07 m의 방사 오프셋을 추가한다. 오프셋은 시작과 착지에서 0이므로 착지점은 바뀌지 않는다.

Swing Height 기본값은 0.20 m이고 몸체 z Offset에 따라 0.05~0.25 m 범위에서 변한다. 진행률 50% 이후 발이 착지점 위 0.03 m 이내에 들어오면 하강 속도를 최대 0.12 m/s로 제한한다.

## 10. 접촉 적응

압력센서는 1 ms마다 여섯 채널만 먼저 읽는다. 접촉 진입 임계값을 넘으면 10 ms 검사 창을 열고, 해제 임계값보다 접촉 쪽인 표본이 10개 중 8개 이상일 때 CONTACT를 확정한다. 확정 접촉은 해제 임계값을 10 ms 연속 넘을 때 해제한다. 실제 임계값과 방향은 센서 캘리브레이션을 사용하며 새 접촉 후보는 다음 5 ms 제어가 소비할 때까지 Latch한다.

Early Landing은 Swing 진행률 50% 이후의 하강 구간에서 접촉이 검출될 때 판단한다. 해당 다리는 현재 발끝 위치를 저장하고 즉시 STANCE로 전환한다.

접촉 순간 관절 ADC와 PWM 예측을 결합한 추정 관절각으로 FK를 계산하고 발 궤적 메모리를 같은 위치에 고정한다. Tripod의 확정 접촉 발에서 공통 Z 오차를 구하고 0.5 mm 데드밴드 초과분의 100%를 최대 0.10 m까지 복구 후보로 사용한다. STANCE에서는 0.25초 Smoothstep S-curve로 적용한다.

정상 Swing 시간이 끝났는데 접촉하지 못하면 Late Landing으로 전환한다. 발을 -Z 방향으로 0.12 m/s로 내리면서 다리 안쪽으로 0.048 m/s 이동시킨다. 모든 Swing 다리와 지지발의 접촉이 확정되기 전에는 다음 Tripod Phase로 넘어가지 않는다.

Late Landing은 최대 0.10 m, 즉 현재 하강 속도에서 약 0.833 s 동안 탐색한다. 한계에 도달하면 발 목표와 서보 전원을 유지한 채 보행을 정지한다. 현재 구현은 이를 Controller Fault로 승격하지 않으며, 조종 입력을 해제한 뒤 다시 보행을 시작해야 한다.

## 11. 작업공간 제한과 연속성

사용자 출력 범위는 Roll·Pitch ±45 deg, x 속도 ±0.10 m/s, y 속도 ±0.07 m/s와 Yaw ±18 deg/s로 제한한다. 실제 적용값은 현재 발 배치에서 6개 다리가 모두 IK 가능한 범위로 동적으로 제한한다.

한 주기의 자세 후보가 가능하면 Roll·Pitch·Yaw 증분을 함께 적용한다. 한 다리라도 불가능하면 세 축을 모두 직전 유효 명령으로 유지한다. 작은 연속 입력을 전제로 하므로 최대 가능값을 찾는 이분 탐색은 사용하지 않는다.

x·y 속도와 사용자 Yaw 회전의 새 후보는 다음 위상 직전에 검사한다. 다음 위상의 시작·중앙·끝 세 지점을 한 5 ms 제어 안에서 검사하며, 각 지점에서 실제 Tripod 역할에 맞는 여섯 발을 함께 구성한다. 세 지점이 모두 유효하면 후보를 두 걸음 묶음에 적용하고, 하나라도 위험하면 다음 위상 진입을 거부한다. 후보 거부는 Controller Fault로 처리하지 않는다. Heading PI 보정은 사용자 명령 기억과 분리하여 매 주기 최신값을 적용한다.

보정 x·y·z 이동은 다음 위치 후보가 불가능하면 바깥 방향 속도를 0으로 만들고 위치 적분 상태도 갱신하지 않는다. 안쪽 복귀 명령은 즉시 허용한다.

최종 IK 앞에는 0.001 m 링크 여유를 둔다. 링크 경계 제한 뒤에도 관절 범위를 벗어나면 기본 발 위치와 입력 사이의 유효 경계로 발 목표를 제한한다. 정상 동작에서 이 마지막 제한이 큰 위치 보정을 수행하면 상위 동적 제한 오류로 판단한다.

## 12. 기구학과 관절 출력

각 발끝 목표는 몸체 좌표계에서 다리 로컬 좌표계로 변환한 뒤 Yaw-Pitch-Pitch 3DOF IK로 관절각을 계산한다. IK는 해 존재 여부와 -135~135 deg 관절 범위를 함께 검사한다.

18개 관절 명령은 -135~135 deg로 제한한 뒤 관절별 방향, 영점과 Pulse 보정을 적용하여 실측 최소~최대 Pulse 범위의 200 Hz PWM으로 출력한다. 현재 `ServoPwm_WriteAngles()`에는 운용 중 관절 명령 변화율 제한이 없으며, 서기 전 초기 관절각을 0 deg로 맞추는 구간만 30 deg/s로 이동한다. 관절 추정기는 PWM 명령의 예측 변화를 300 deg/s로 제한해 ADC 절대각과 결합한다.

## 13. Safety

현재 Safety는 다음 조건을 평가한다.

| Fault | 조건 |
|---|---|
| Rollover Fault | 유효한 IMU Roll 또는 Pitch의 절댓값이 80 deg 이상 |
| Controller Fault | IMU 비유한수 또는 최종 IK Invalid가 3회 연속 발생 |

두 Fault는 한 번 발생하면 Latch되며 Reset 입력을 두지 않는다. Fault가 발생하면 상위 상태가 FAULT로 전환되고 Kill 동작으로 6개 서보 전원 릴레이를 모두 끈다. 자동 Recovery는 수행하지 않는다.

다음 항목은 설계 후보이지만 현재 Safety 판정에는 아직 포함하지 않는다.

- Safe Support Polygon
- 비정상 Joint Jump
- 센서별 Timeout
- Stance Foot Slip Fault 승격

관절 범위와 발끝 작업공간 제한은 Safety Latch와 별개로 항상 적용하는 출력 보호이다. Late Landing 한계 정지는 전원을 차단하지 않는 별도 보행 정지 상태이다.

## 14. 시험 원칙

시험은 센서와 기구학부터 시작해 실제 서보 출력으로 범위를 넓힌다.

1. 좌표축, 관절 방향과 FK/IK를 검증한다.
2. 압력센서 CONTACT/RELEASE를 튜닝한다.
3. Stance와 Swing 궤적을 서보 전원 없이 확인한다.
4. Position PI와 Heading PI를 낮은 Gain으로 조정한다.
5. Roll·Pitch와 보정 Yaw 자세 PI를 조정한다.
6. 작업공간 제한과 모드 전환 연속성을 확인한다.
7. IK Invalid와 전복 입력에서 Safety Latch와 릴레이 차단을 확인한다.
8. 낮은 속도에서 시작해 x 0.10 m/s, y 0.07 m/s와 Yaw 18 deg/s까지 단계적으로 실기 검증한다.

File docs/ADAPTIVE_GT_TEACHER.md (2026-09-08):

# GT 전진 완주 학습

현재 방향은 yaw 조종을 제외한 전진 지형 완주다. `hybrid` profile과 `terrain` command mode를 사용한다.
Terrain 기본 yaw 명령은 0이고 RC의 회전·후진·정지 sampler는 사용하지 않는다.
직진 중 회전 억제를 위한 yaw 안정화 보상은 유지한다. Residual 범위와 접촉/IK 안전은 그대로다.

## 실행

RC checkpoint는 task가 다르므로 아래 첫 실행에는 restore하지 않는다.

```bash
cd /home/huro/Hexapod-Robot-integration
source /home/huro/.venvs/hexapod-mjx/bin/activate

bash scripts/train_adaptive_curriculum.sh \
  --profile hybrid \
  --command-mode terrain \
  --perception teacher \
  --run-name adaptive-gt-forward-completion \
  --timesteps-per-stage 800000 \
  --num-envs 512 --batch-size 128 --num-minibatches 4 \
  --num-evals 5 --num-eval-envs 16 --episode-length 8000 \
  --action-profile terrain_mid --discounting 0.997 \
  --baseline-comparison-seconds 20 --best-video-duration 40 \
  --promote-key eval/episode_terrain_success --promote-threshold 0.70 \
  --max-retries -1 --on-stage-failure stop \
  --wandb --wandb-mode online
```

완주율 70% 미달이면 무제한 retry하며 실패한 지형을 자동으로 넘기지 않는다.
모든 지형 Hybrid 순서: flat → ramp8 → stair5 → stair8 → rough25 → ramp15 → stair10 → rough50.
이후 stair15/stair20으로 진행한다. 모든 stage의 gait는 Hybrid(stage 3)다. GT는 actor grid와 planner에 사용한다.
학습·시뮬레이션은 사용자가 실행한다.

## 기본 보행과 정책 비교

매 cycle 종료 후 **그 cycle의 best checkpoint**와 **24-D zero-action**을 비교한다.
두 개의 같은 reset seed, 같은 환경/명령 sampler, 같은 최대 20초 horizon을 사용한다.
환경 종료 후 재시작하지 않고 결과를 고정한다. 20초에 끝나지 않으면 truncated로 표시하며
성공으로 간주하지 않는다. forward_m는 시작 몸체 전방으로 투영한 순변위여서 회전 명령이
있는 episode에서는 전체 경로 길이를 뜻하지 않는다.

이 비교는 학습 업데이트에 사용하지 않는다. PPO reward/best 선정, promotion의
`eval/episode_terrain_success`를 변경하지 않는다. 영상은 이전처럼 cycle best policy를
별도 영상 seed로 재생하며, paired 비교 seed의 영상이라고 주장하지 않는다.
전체 curriculum 누적 best 영상은 추가하지 않는다.

W&B 확인 항목:

- `comparison/baseline/forward_m`, `comparison/policy/forward_m`
- `comparison/*/hold_planner_s`, `comparison/*/hold_contact_wait_s`
- `comparison/*/success`, `comparison/*/no_progress`, `comparison/*/truncated`
- `comparison/policy_minus_baseline_forward_m`
- 기존 `cycle/best_score`, `cycle/best_video`, `cycle/best_video_status`

baseline과 policy가 모두 멈추면 planner/contact 문제를 먼저 확인한다. baseline만 잘 걸으면
residual/reward를 확인한다. 두 seed의 짧은 결과는 진단 표본이지 보행 성능의 확증이 아니다.
비교 실패는 `comparison/error`와 `monitor/baseline_comparison_error.json`에 기록하고
best 영상 생성은 계속 시도한다. 정상 결과 파일은 `monitor/baseline_comparison.json`이다.

`--baseline-comparison-seconds 0`이면 비교를 끈다. teacher profile 기본값은 20초,
기존 profile 기본값은 0이다. 비교에는 추가 JIT/rollout 비용이 들며 처리량은 측정하지 않았다.

GT teacher가 안정적으로 개선된 다음 LiDAR student 증류와 PPO fine-tuning을 진행한다.
이번 변경에는 자동 teacher-student 증류를 구현하지 않았다. 단순 입력 교체를 증류로 보지 않는다.

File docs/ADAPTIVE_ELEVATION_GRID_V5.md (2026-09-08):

# Elevation grid 기반 residual RL — 관측/network v5

## PPO 초기화 shape 오류 수정

Brax PPO는 관측 크기를 `{'state': (7890,), ...}`로 전달하지만 초기 CNN 코드는
정수 크기만 가정해 `(1, (7890,))` 배열을 만들려 했다. actor/critic 모두 정수,
1-D tuple, JSON list를 정수 폭으로 정규화하도록 수정했다. 동작/관측/network 차원은
변경하지 않았다. 해당 오류는 네트워크 초기화 단계에서 발생했으므로 그 실패 run에는
복원할 학습 checkpoint가 없다. 아래 학습 명령에서 run-name만
`adaptive-grid-v5-lidar-mid-shapefix`로 변경하고 restore 없이 다시 실행한다.
회귀 테스트는 추가했으며 실행은 사용자에게 맡긴다.

## 구현 범위와 실행 상태

`codex/adaptive-hybrid-rl-integration`에서 수정했다. 이번 변경의 simulation,
PPO, unit test, hardware 실행은 모두 사용자에게 맡긴다. 보행 성공을 확인한 버전이라는
의미가 아니다. 기존 학습 프로세스를 시작하거나 종료하지 않는다.

물리적 action은 `adaptive_hybrid_geometry_residual_24_v4`를 유지한다.
관측은 `adaptive_hybrid_elevation_grid24x24x6_v5`, network는
`elevation_cnn_16_32_dense64_v1`로 분리했다. 기존 v4 checkpoint는 호환 오류로
거부한다. `--restore`나 `--migrate-flat-boxes`로 이전 네트워크를 우회 로드하지 않는다.
기존 run 기록/가중치를 삭제하거나 덮어쓰지 않는다. 진행 중인 이전 학습은 새 구조로
전환되지 않으며, 이전 checkpoint에서 다음 subprocess를 시작하면 계약 불일치가 난다.
이전 run을 이어갈 때는 그 checkpoint에 기록된 source revision을 별도 checkout해야 한다.

## 데이터 흐름

```text
LiDAR returns → 64×64 rolling elevation map (5 cm)
                      ├→ wide/local foothold geometry → safe reference
                      └→ body-yaw-aligned 24×24×6 local grid → CNN
robot/gait/contact/candidate vector ────────────────────────────┤
                                                              ↓
                                                         24-D residual
                                                              ↓
                          feasible stride / landing / clearance projection
                                                              ↓
                                            latched classical gait + safety
```

LiDAR 모드에서는 actor grid와 foothold geometry 모두 센서 지도를 사용한다.
teacher/oracle은 명시적으로 GT를 사용하며 LiDAR 학습 결과와 구분한다.

로컬 grid는 몸체를 중심으로 앞/왼쪽 방향에 정렬된 약 1.2 m 정사각형이다.
6개 채널은 몸체 기준 상대 높이, known, confidence, age, 전방 slope, 좌측 slope다.
unknown의 높이/slope는 0으로 mask하고 known/confidence=0, age=1을 전달한다.
이는 unknown을 안전한 평면으로 판정하는 동작이 아니다.
confidence는 관측 age와 최근 spread의 휴리스틱이며 보정된 확률값은 아니다.

CNN: Conv 3×3 stride 2, 16 channels → Conv 3×3 stride 2, 32 channels → flatten → Dense 64.
이 latent와 기존 4,434-D vector를 결합해 256/256/128 MLP로 정책을 만든다.
actor 입력은 **7,890-D**, critic은 **8,205-D**다. actor와 critic encoder는 독립적이다.
grid의 물리적 채널 scaling은 유지하고 기존 vector는 PPO running normalization을 사용한다.
normalizer 저장 형식은 전체 observation을 유지하므로 메모리/처리량은 실측이 필요하다.

Viewer의 M 지도 표시는 점 대신 5 cm 반투명 사각 셀로 그린다.
이 시각화 변경 때문에 viewer를 자동 실행하지 않는다.

## 불필요한 정지 수정

1. **셀 lifetime min/max 누적 제거**: 최신 scan 상단 높이를 대표값으로 채택한다.
   spread는 현재 scan 범위, 직전 scan과의 높이 변화, 시간상수 2초로 감쇠한 과거 spread의
   최댓값이다. 반복되는 실제 단차는 유지하고 오래된 단일 극값은 감쇠한다.
   미관측 셀의 값/타임스탬프는 갱신하지 않는다. MJX와 Jetson은 같은 fusion 함수를 사용한다.
   이것은 robust quantile/다중 surface estimator가 아니며 센서 노이즈에 대한 보정은 남아 있다.
2. **보폭은 선호값**: 요청 이하에 safe stride가 있으면 그중 가장 큰 값을 사용한다.
   없으면 전체 feasible set에서 요청에 가장 가까운 값을 선택한다. 안전한 stride가 있는데
   RL 요청보다 크다는 이유만으로 HOLD하지 않는다. Tripod oversize 1.3은 normal 1.0이
   가능한 경우에만 허용한다. Wave도 동일한 preference projection을 사용한다.
3. **초기 classical handoff**: 한 번 feasible이면 영구 종료하던 조건을 바꿨다.
   normal stride의 현재/다음 Tripod phase가 0.4초 연속 feasible이고 all-contact phase
   boundary에 도달해야 handoff한다. 초기 classical은 기존처럼 stride 0.5, 최대 24 phases다.
   nominal 착지 후보에서 관측된 unsafe terrain은 bootstrap으로 무시하지 않는다.
   fixed Wave stage에서는 Tripod bootstrap을 사용하지 않는다.
4. **정지 원인 기록**: 아래 W&B 지표를 추가했다. 기존 cycle best 영상/score 업로드 경로는 유지한다.

이 변경은 무조건 전진하는 blind controller가 아니다. handoff 이후 완전히 unknown인
다음 착지에 대한 지속적인 contact-inferred creep는 아직 구현하지 않았다.
UNKNOWN→HOLD, 접촉 확인, IK/workspace, path collision, 지지 여유 12mm는 유지한다.
coverage 60%, plane RMS 8mm도 이번에는 임의로 낮추지 않았다.

예측 CoM만 앞으로 옮기는 수정은 적용하지 않았다. 현재 실행 endpoint는 body-frame latch라
CoM만 이동하면 landing frame과 불일치한다. 이후 touchdown 시점 body motion과 landing target을
같은 frame/time으로 모델링한 뒤 support 검사와 map query를 함께 수정해야 한다.

## W&B에서 확인할 것

episode 합산 값은 아래 이름 앞에 `eval/episode_`가 붙는다. 각 tick에 초 단위 dt를
기록하므로 평가 결과는 episode당 평균 대기 시간(초)이다. 원인별 증거는 서로 겹칠 수 있다.
단일 원인으로 확정하는 counter가 아니며, 모든 contact/scheduler freeze를 포괄하지는 않는다.

| 지표 | 의미 |
|---|---|
| `hold_planner_s` | 이동 명령 중 다음 phase가 planner permit을 받지 못한 시간 |
| `hold_contact_wait_s` | 다음 phase 대기 중 all-contact가 아닌 시간 |
| `hold_map_unknown_s` | HOLD 중 active leg의 support coverage 후보가 부족한 시간 |
| `hold_surface_rejected_s` | HOLD 중 active leg 후보에 rough/edge가 관측된 시간 |
| `hold_ik_rejected_s` | HOLD 중 terrain+IK 통과 후보가 없는 active leg가 있는 시간 |
| `hold_path_rejected_s` | HOLD 중 terrain+IK+path+coverage 후보가 부족한 시간 |
| `hold_support_rejected_s` | HOLD 중 선택된 계획의 지지 여유가 12mm 미만인 시간 |
| `bootstrap_classical_s` | 초기 classical proposal이 활성인 시간; 실제 이동 시간과 다름 |
| `stride_preference_projected_s` | feasible projection이 RL 요청보다 큰 stride를 선택한 시간 |

영상에서 정지가 줄었는지와 함께 success, slip, touchdown error, projection, scheduler fault를
확인한다. reward 상승만으로 지형 적응 성공이라고 판정하지 않는다.
3초 no-progress watchdog은 유지했다. 정지 종료를 늦춰 성공처럼 보이게 하지 않는다.

## 사용자 실행 명령

새 network이므로 **restore 없이 새 run**으로 시작한다. 아래 명령은 GUI를 열지 않으며,
기존처럼 cycle별 best 영상과 score를 W&B로 보낸다. 전체 best 영상 추가 저장은 하지 않는다.

```bash
cd /home/huro/Hexapod-Robot-integration
source /home/huro/.venvs/hexapod-mjx/bin/activate
bash scripts/train_adaptive_curriculum.sh \
  --profile full --perception lidar \
  --run-name adaptive-grid-v5-lidar-mid \
  --timesteps-per-stage 800000 \
  --num-envs 512 --batch-size 128 --num-minibatches 4 \
  --num-evals 5 --num-eval-envs 8 --episode-length 8000 \
  --action-profile terrain_mid --best-video-duration 12 \
  --max-retries 3 --on-stage-failure advance \
  --wandb --wandb-mode online
```

`advance`는 실패한 stage도 표시하고 다음 지형을 시도한다. 통과를 의미하지 않는다.
통과한 stage만 진행하려면 `--on-stage-failure stop`을 사용한다.
메모리가 부족하면 `--num-envs 256`으로 낮춘다. 이번 변경의 GPU 사용량/속도는 측정하지 않았다.

사용자용 unit checks (rollout/PPO 없음):

```bash
python -m unittest mjx.tests.test_adaptive_grid mjx.tests.test_adaptive_hybrid mjx.tests.test_adaptive_v4
```

새 tests는 오래된 outlier 감쇠/실제 반복 단차 유지, 미관측 셀 age 보존, grid yaw/mask,
stride fallback, CNN batch shape와 grid gradient를 확인한다. 이번 작업에서는 실행하지 않았다.

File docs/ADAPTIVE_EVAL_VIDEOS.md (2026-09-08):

> 현재 권장: **v6 수정 + 기존 계단 가중치**는
> `bash /home/huro/Hexapod-Robot-integration/scripts/resume_stair5_path_v6.sh`를 사용한다.
> 아래의 v5 전용 재개/이전 미지원 설명은 이전 상태다. `--migrate-path-v6`가
> d0370b3의 terrain v5 source 전체 hash를 확인한 뒤 명시적으로 이전한다.
> 이전 가중치의 원본 파일은 변경하지 않는다. 실행/학습 검증은 아직 하지 않았다.

# 매 평가 현재 정책 영상

`--best-video`를 켜면 학습 후 평가마다 **현재 정책**을 렌더링한다.
W&B `cycle/current_video`, `cycle/current_score`, `cycle/current_step`을 확인한다.
Best는 완주율 우선, 동률이면 reward로 계속 보존한다.
Best가 갱신된 평가에서만 `cycle/best_video`와 best-policy artifact를 추가한다.
해당 평가의 현재 영상을 재사용하므로 rollout을 두 번 실행하지 않는다.
초기 step 0 및 cycle 종료 중복 영상은 제외한다.

현재 영상은 `videos/eval_<step>_current.gif`, 연결 정보는
`monitor/current_video_<step>.json`에 저장한다. 모든 평가 checkpoint는
current-policy artifact에 기록하며 best는 별도 best-policy artifact로 보관한다.
Best가 같더라도 current 영상은 새 checkpoint의 실제 정책을 보여준다.
동일 seed/명령 조건으로 비교하지만 단일 영상의 결과는 평가 성공률과 다를 수 있다.

재개 preset: 학습량 800000, 평가 설정 9, 평가 env 16, 영상 최대 20초,
추가 baseline 비교 0. Brax의 초기 평가를 제외한 학습 후 평가는 보통 8회이며
실제 간격은 PPO batch 단위로 결정된다(현재 구성에서 약 102400 step).
영상은 동기식으로 생성하므로 PPO가 기다리며, 평가 횟수 증가가 전체 학습을
더 빠르게 만든다는 의미는 아니다. 학습/영상 검증은 사용자에게 맡긴다.

## 지정 GIF의 checkpoint

`best_video_7_0e1017aebbbc13860373.gif`는 로컬 best.gif와 SHA256이 일치한다.
저장된 best pointer의 checkpoint는 다음이다.

```text
/home/huro/Hexapod-Robot-integration/mjx/runs/adaptive-curriculum/forward-gt-terrain-mid/02_tripod-stair5_try02/checkpoints/000000204800
```

Recorded source: `d0370b3f30b0d3c83541c61a1df44bc87ebcf7d7`, terrain task, v5 관측.
저장된 모든 controller/source hash가 해당 revision과 일치하는 것을 파일 읽기로 확인했다.
v6는 입력 차원이 달라 직접 restore할 수 없다. 따라서 재개 브랜치
`codex/stair5-eval-video-resume`는 기록된 v5 소스에 영상 callback 변경만 선택 적용한다.
이 경로에는 v6 경로 bottleneck 보정이 없다. v6 자동 가중치 이전을 구현하지 않았다.

```bash
cd /home/huro/Hexapod-Robot-stair5-resume
source /home/huro/.venvs/hexapod-mjx/bin/activate
checkpoint=/home/huro/Hexapod-Robot-integration/mjx/runs/adaptive-curriculum/forward-gt-terrain-mid/02_tripod-stair5_try02/checkpoints/000000204800
bash scripts/train_adaptive_curriculum.sh \
  --profile teacher --command-mode terrain --perception teacher \
  --start-index 2 --restore "$checkpoint" \
  --run-name stair5-best-eval-video-resume \
  --run-root /home/huro/Hexapod-Robot-integration/mjx/runs/adaptive-curriculum \
  --timesteps-per-stage 800000 \
  --num-envs 512 --batch-size 128 --num-minibatches 4 \
  --num-evals 5 --num-eval-envs 16 --episode-length 8000 \
  --action-profile terrain_mid --discounting 0.997 \
  --best-video-duration 40 --baseline-comparison-seconds 20 \
  --promote-key eval/episode_terrain_success --promote-threshold 0.70 \
  --max-retries -1 --on-stage-failure stop \
  --wandb-project hexapod-forward-completion --wandb --wandb-mode online
```

Teacher curriculum index 2는 stage 1 Tripod, terrain level 5다.
이후 완주율 70%를 통과하면 다음 지형으로 진행한다.
학습/시뮬레이션/영상 생성은 실행하지 않았다. 문법과 source hash만 확인했다.

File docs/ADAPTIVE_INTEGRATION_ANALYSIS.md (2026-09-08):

# Adaptive integration 분석 및 결정

2026-09-07. main source: `9752c760002ac2dc7cc493ed634a881f87b7fd1e`.
실제 base는 후속 URDF-only commit `de77791d6386309295be5c8d173a1f51eca99930`이다.
두 revision 사이 STM32 변경은 없다. adaptive source는 `f9d80587ff086a1f3df51b81185e742094c109c9`.
전체 merge 없이 main에서 `codex/adaptive-hybrid-rl-integration`을 만들었다.

## 변경 전 분석

- main RL은 session / observation history 32 / age 60 ms / command timeout 100 ms /
  wrap-aware sequence / plan ID+mask 검증을 갖췄다. Workspace의 9-point preflight 후
  FootTrajectory pending→active latch가 있다. 입력 RobotRlAction은 absolute posture와 dx/dy/dz/dh다.
- main manual은 phase 1초, cubic XY+parabolic Z+radial 7 cm, swing 20 cm다.
  Wave 0,5,1,3,2,4; speed .2; stance 5 phase; 첫 순회 half stance를 사용한다.
  Early .5, Late .12 m/s·inward .096 m/s·10 cm 한계, support recovery와 전원 안전이 우선이다.
- MJX adaptive v3는 action24, actor4410/critic4725. wide25 후보를 local projection에도
  재사용해서 X를 decoder에서 늘려도 실제 ±6 cm endpoint가 없다. Tripod .5초도 main과 다르다.
- correction body_offset는 사용자 속도의 적분 translation이다. adaptive body height는
  phase별 absolute offset이므로 별도 state와 rate/workspace gate가 필요하다.
- main SPI v2는 raw 24-byte payload 보관까지이며 RL API와 연결되지 않았다.
  Jetson 폴더에는 실행 코드가 없다. ISR은 완료 flag만 기록해야 한다.

## 통합 결정

1. main의 HW/STM32를 유지하고 adaptive root mjx subtree(legacy replay 의존성·가중치 포함),
   viewer/train wrapper 3개와 관련 docs 4개만 선택적으로 가져온다. SW/mjx·다른 firmware는 가져오지 않는다.
2. PolicyAction24 v4와 final AdaptiveExecutionPlan을 분리한다. geometry가 Z를 소유한다.
3. wide ±8 cm grid와 local X ±6/Y ±4 cm grid를 분리한다. map 5 cm는 유지한다.
4. adaptive timing/trajectory 상수를 양쪽에 명시하고 golden tests로 drift를 검출한다.
5. final target frame, body offset, gait negotiation, freshness/latch를 내부 API에서 먼저 고정한다.
6. SPI는 마지막에 128-byte explicit little-endian fixed-point/CRC로 연결한다.
7. manual/legacy trajectory와 안전 상태기는 유지한다. 새 기능은 adaptive 실행에서만 선택한다.

빌드·단위 계약 확인은 최소 범위로 진행한다. Stage0 viewer, PPO, 보드 플래시와 물리 동작은
사용자 검증이며 코드 구현과 구분한다. 전체 변경 파일과 검증 결과는 최종 통합 보고서에 기록한다.

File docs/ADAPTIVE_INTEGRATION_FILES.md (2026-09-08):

# Integration file manifest

Base main: `de77791d6386309295be5c8d173a1f51eca99930`. Adaptive source: `f9d80587ff086a1f3df51b81185e742094c109c9`.
No merge commit; import commit `c5441de` selectively restores adaptive files.

## main 기반 STM32 확장 파일

- `SW/STM32/workspace/Hexapod/Core/Inc/app/hexapod_app.h`
- `SW/STM32/workspace/Hexapod/Core/Inc/common/robot_config.h`
- `SW/STM32/workspace/Hexapod/Core/Inc/common/robot_types.h`
- `SW/STM32/workspace/Hexapod/Core/Inc/communication/adaptive_spi_protocol.h`
- `SW/STM32/workspace/Hexapod/Core/Inc/communication/jetson_spi.h`
- `SW/STM32/workspace/Hexapod/Core/Inc/high_control/foot_trajectory.h`
- `SW/STM32/workspace/Hexapod/Core/Inc/high_control/gait_manager.h`
- `SW/STM32/workspace/Hexapod/Core/Inc/high_control/rl_controller.h`
- `SW/STM32/workspace/Hexapod/Core/Inc/high_control/swing_trajectory.h`
- `SW/STM32/workspace/Hexapod/Core/Inc/high_control/workspace_limiter.h`
- `SW/STM32/workspace/Hexapod/Core/Src/app/hexapod_app.c`
- `SW/STM32/workspace/Hexapod/Core/Src/communication/adaptive_spi_protocol.c`
- `SW/STM32/workspace/Hexapod/Core/Src/communication/jetson_spi.c`
- `SW/STM32/workspace/Hexapod/Core/Src/high_control/foot_trajectory.c`
- `SW/STM32/workspace/Hexapod/Core/Src/high_control/gait_manager.c`
- `SW/STM32/workspace/Hexapod/Core/Src/high_control/rl_controller.c`
- `SW/STM32/workspace/Hexapod/Core/Src/high_control/swing_trajectory.c`
- `SW/STM32/workspace/Hexapod/Core/Src/high_control/workspace_limiter.c`

## 선택적 import commit 파일

`docs/ADAPTIVE_INTEGRATION_ANALYSIS.md`는 새 분석 문서이며 나머지는 adaptive source에서 가져왔다.

- `docs/ADAPTIVE_INTEGRATION_ANALYSIS.md`
- `docs/HEXAPOD_FOOTHOLD_PREVIEW_USAGE.md`
- `docs/HEXAPOD_HYBRID_GAIT_ANALYSIS.md`
- `docs/HEXAPOD_MJX_ADAPTIVE_GAIT_LEARNING_PLAN.md`
- `docs/HEXAPOD_MJX_ADAPTIVE_GAIT_USAGE.md`
- `mjx/.gitignore`
- `mjx/FIRMWARE_BASE.md`
- `mjx/RL_DESIGN.md`
- `mjx/adaptive_foothold_estimator.py`
- `mjx/adaptive_gait_controller.py`
- `mjx/adaptive_gait_env.py`
- `mjx/adaptive_gait_perception.py`
- `mjx/adaptive_gait_policy.py`
- `mjx/benchmark_hexapod_vs_go1.py`
- `mjx/continuous_foothold_gait.py`
- `mjx/domain_randomization.py`
- `mjx/export_asset_manifest.py`
- `mjx/export_isaac_asset_mjcf.py`
- `mjx/export_isaac_contract.py`
- `mjx/firmware_controller.py`
- `mjx/firmware_mjx_controller.py`
- `mjx/foothold_feasibility.py`
- `mjx/foothold_link_model.py`
- `mjx/foothold_planner.py`
- `mjx/foothold_policy_adapter.py`
- `mjx/foothold_policy_controller.py`
- `mjx/foothold_policy_observation.py`
- `mjx/foothold_policy_scene.py`
- `mjx/foothold_policy_worker.py`
- `mjx/foothold_preview_runtime.py`
- `mjx/foothold_preview_scene.py`
- `mjx/golden/asset_manifest_v1.json`
- `mjx/golden/isaac_contract_v1_flat_seed0.json`
- `mjx/golden/isaac_contract_v1_flat_seed0.npz`
- `mjx/hybrid_gait_supervisor.py`
- `mjx/lidar_extrinsics.py`
- `mjx/mid360_profile.py`
- `mjx/native/firmware_controller_bridge.c`
- `mjx/policies/progress-v2-stage31-level6/README.md`
- `mjx/policies/progress-v2-stage31-level6/environment.json`
- `mjx/policies/progress-v2-stage31-level6/manifest.json`
- `mjx/policies/progress-v2-stage31-level6/recorded_score.json`
- `mjx/policies/progress-v2-stage31-level6/weights/_CHECKPOINT_METADATA`
- `mjx/policies/progress-v2-stage31-level6/weights/_METADATA`
- `mjx/policies/progress-v2-stage31-level6/weights/_sharding`
- `mjx/policies/progress-v2-stage31-level6/weights/array_metadatas/process_0`
- `mjx/policies/progress-v2-stage31-level6/weights/d/e5c320be86dcdc2c2ccced0a023af177`
- `mjx/policies/progress-v2-stage31-level6/weights/manifest.ocdbt`
- `mjx/policies/progress-v2-stage31-level6/weights/ocdbt.process_0/d/58917114a525aaeb2369c6990415ff52`
- `mjx/policies/progress-v2-stage31-level6/weights/ocdbt.process_0/d/7798773c7346869051ab8dd63c41e8d0`
- `mjx/policies/progress-v2-stage31-level6/weights/ocdbt.process_0/d/a57d5c38e7a862e90d7e455739458e3d`
- `mjx/policies/progress-v2-stage31-level6/weights/ocdbt.process_0/d/dfc74eb818d5b3340effa4251c6f2d5c`
- `mjx/policies/progress-v2-stage31-level6/weights/ocdbt.process_0/manifest.ocdbt`
- `mjx/policies/progress-v2-stage31-level6/weights/ppo_network_config.json`
- `mjx/policy_video.py`
- `mjx/prepare_rl_scene.py`
- `mjx/prepare_scene.py`
- `mjx/prepare_urdf.py`
- `mjx/requirements-train.txt`
- `mjx/requirements.txt`
- `mjx/rough_terrain_env.py`
- `mjx/run_controller.py`
- `mjx/run_firmware_base.py`
- `mjx/servo_model.py`
- `mjx/teacher_distillation.py`
- `mjx/teacher_manifests/walking-teachers-v1.json`
- `mjx/terrain_curriculum.py`
- `mjx/tests/run_pitch_smoke_e2e.py`
- `mjx/tests/test_adaptive_hybrid.py`
- `mjx/tests/test_cli_and_gate.py`
- `mjx/tests/test_command_inputs.py`
- `mjx/tests/test_command_space.py`
- `mjx/tests/test_domain_randomization.py`
- `mjx/tests/test_firmware_mjx_controller.py`
- `mjx/tests/test_isaac_contract_artifacts.py`
- `mjx/tests/test_pitch_ff.py`
- `mjx/tests/test_servo_model.py`
- `mjx/tests/test_stair_penalties.py`
- `mjx/tests/test_swing_boost.py`
- `mjx/tests/test_teacher_distillation.py`
- `mjx/tests/test_training_artifacts.py`
- `mjx/tests/verify_plan_anchors.py`
- `mjx/train_adaptive_gait.py`
- `mjx/train_competence_curriculum.py`
- `mjx/train_rough_terrain.py`
- `mjx/tripod_controller.py`
- `mjx/view_adaptive_gait.py`
- `mjx/view_foothold_explorer.py`
- `mjx/view_foothold_planner.py`
- `mjx/view_rl_scene.py`
- `mjx/view_robot.py`
- `mjx/view_trained_policy.py`
- `mjx/wave_gait_scheduler.py`
- `scripts/train_adaptive_gait.sh`
- `scripts/view_foothold_planner.sh`
- `scripts/view_trained_policy.sh`

## 최종 변경 파일 전체 (main 대비 130개)

- `.gitignore`
- `README.md`
- `SW/Jetson/README.md`
- `SW/Jetson/adaptive_execution_plan.py`
- `SW/Jetson/adaptive_policy_contract.py`
- `SW/Jetson/adaptive_runtime.py`
- `SW/Jetson/adaptive_spi_protocol.py`
- `SW/Jetson/make_offline_fixture.py`
- `SW/STM32/SB_RL_GAIT_SPI_CHANGE_PLAN.md`
- `SW/STM32/workspace/Hexapod/Core/Inc/app/hexapod_app.h`
- `SW/STM32/workspace/Hexapod/Core/Inc/common/robot_config.h`
- `SW/STM32/workspace/Hexapod/Core/Inc/common/robot_types.h`
- `SW/STM32/workspace/Hexapod/Core/Inc/communication/adaptive_spi_protocol.h`
- `SW/STM32/workspace/Hexapod/Core/Inc/communication/jetson_spi.h`
- `SW/STM32/workspace/Hexapod/Core/Inc/high_control/foot_trajectory.h`
- `SW/STM32/workspace/Hexapod/Core/Inc/high_control/gait_manager.h`
- `SW/STM32/workspace/Hexapod/Core/Inc/high_control/rl_controller.h`
- `SW/STM32/workspace/Hexapod/Core/Inc/high_control/swing_trajectory.h`
- `SW/STM32/workspace/Hexapod/Core/Inc/high_control/workspace_limiter.h`
- `SW/STM32/workspace/Hexapod/Core/Src/app/hexapod_app.c`
- `SW/STM32/workspace/Hexapod/Core/Src/communication/adaptive_spi_protocol.c`
- `SW/STM32/workspace/Hexapod/Core/Src/communication/jetson_spi.c`
- `SW/STM32/workspace/Hexapod/Core/Src/high_control/foot_trajectory.c`
- `SW/STM32/workspace/Hexapod/Core/Src/high_control/gait_manager.c`
- `SW/STM32/workspace/Hexapod/Core/Src/high_control/rl_controller.c`
- `SW/STM32/workspace/Hexapod/Core/Src/high_control/swing_trajectory.c`
- `SW/STM32/workspace/Hexapod/Core/Src/high_control/workspace_limiter.c`
- `docs/ADAPTIVE_INTEGRATION_ANALYSIS.md`
- `docs/ADAPTIVE_INTEGRATION_FILES.md`
- `docs/ADAPTIVE_INTEGRATION_V4.md`
- `docs/ADAPTIVE_SPI_V3.md`
- `docs/HEXAPOD_FOOTHOLD_PREVIEW_USAGE.md`
- `docs/HEXAPOD_HYBRID_GAIT_ANALYSIS.md`
- `docs/HEXAPOD_MJX_ADAPTIVE_GAIT_LEARNING_PLAN.md`
- `docs/HEXAPOD_MJX_ADAPTIVE_GAIT_USAGE.md`
- `mjx/.gitignore`
- `mjx/FIRMWARE_BASE.md`
- `mjx/RL_DESIGN.md`
- `mjx/adaptive_contract.py`
- `mjx/adaptive_foothold_estimator.py`
- `mjx/adaptive_gait_controller.py`
- `mjx/adaptive_gait_env.py`
- `mjx/adaptive_gait_perception.py`
- `mjx/adaptive_gait_policy.py`
- `mjx/benchmark_hexapod_vs_go1.py`
- `mjx/continuous_foothold_gait.py`
- `mjx/domain_randomization.py`
- `mjx/export_asset_manifest.py`
- `mjx/export_isaac_asset_mjcf.py`
- `mjx/export_isaac_contract.py`
- `mjx/firmware_controller.py`
- `mjx/firmware_mjx_controller.py`
- `mjx/foothold_feasibility.py`
- `mjx/foothold_link_model.py`
- `mjx/foothold_planner.py`
- `mjx/foothold_policy_adapter.py`
- `mjx/foothold_policy_controller.py`
- `mjx/foothold_policy_observation.py`
- `mjx/foothold_policy_scene.py`
- `mjx/foothold_policy_worker.py`
- `mjx/foothold_preview_runtime.py`
- `mjx/foothold_preview_scene.py`
- `mjx/golden/asset_manifest_v1.json`
- `mjx/golden/isaac_contract_v1_flat_seed0.json`
- `mjx/golden/isaac_contract_v1_flat_seed0.npz`
- `mjx/hybrid_gait_supervisor.py`
- `mjx/lidar_extrinsics.py`
- `mjx/mid360_profile.py`
- `mjx/native/firmware_controller_bridge.c`
- `mjx/policies/progress-v2-stage31-level6/README.md`
- `mjx/policies/progress-v2-stage31-level6/environment.json`
- `mjx/policies/progress-v2-stage31-level6/manifest.json`
- `mjx/policies/progress-v2-stage31-level6/recorded_score.json`
- `mjx/policies/progress-v2-stage31-level6/weights/_CHECKPOINT_METADATA`
- `mjx/policies/progress-v2-stage31-level6/weights/_METADATA`
- `mjx/policies/progress-v2-stage31-level6/weights/_sharding`
- `mjx/policies/progress-v2-stage31-level6/weights/array_metadatas/process_0`
- `mjx/policies/progress-v2-stage31-level6/weights/d/e5c320be86dcdc2c2ccced0a023af177`
- `mjx/policies/progress-v2-stage31-level6/weights/manifest.ocdbt`
- `mjx/policies/progress-v2-stage31-level6/weights/ocdbt.process_0/d/58917114a525aaeb2369c6990415ff52`
- `mjx/policies/progress-v2-stage31-level6/weights/ocdbt.process_0/d/7798773c7346869051ab8dd63c41e8d0`
- `mjx/policies/progress-v2-stage31-level6/weights/ocdbt.process_0/d/a57d5c38e7a862e90d7e455739458e3d`
- `mjx/policies/progress-v2-stage31-level6/weights/ocdbt.process_0/d/dfc74eb818d5b3340effa4251c6f2d5c`
- `mjx/policies/progress-v2-stage31-level6/weights/ocdbt.process_0/manifest.ocdbt`
- `mjx/policies/progress-v2-stage31-level6/weights/ppo_network_config.json`
- `mjx/policy_video.py`
- `mjx/prepare_rl_scene.py`
- `mjx/prepare_scene.py`
- `mjx/prepare_urdf.py`
- `mjx/requirements-train.txt`
- `mjx/requirements.txt`
- `mjx/rough_terrain_env.py`
- `mjx/run_controller.py`
- `mjx/run_firmware_base.py`
- `mjx/servo_model.py`
- `mjx/teacher_distillation.py`
- `mjx/teacher_manifests/walking-teachers-v1.json`
- `mjx/terrain_curriculum.py`
- `mjx/tests/run_pitch_smoke_e2e.py`
- `mjx/tests/test_adaptive_hybrid.py`
- `mjx/tests/test_adaptive_v4.py`
- `mjx/tests/test_cli_and_gate.py`
- `mjx/tests/test_command_inputs.py`
- `mjx/tests/test_command_space.py`
- `mjx/tests/test_domain_randomization.py`
- `mjx/tests/test_firmware_mjx_controller.py`
- `mjx/tests/test_isaac_contract_artifacts.py`
- `mjx/tests/test_pitch_ff.py`
- `mjx/tests/test_servo_model.py`
- `mjx/tests/test_stair_penalties.py`
- `mjx/tests/test_swing_boost.py`
- `mjx/tests/test_teacher_distillation.py`
- `mjx/tests/test_training_artifacts.py`
- `mjx/tests/verify_plan_anchors.py`
- `mjx/train_adaptive_gait.py`
- `mjx/train_competence_curriculum.py`
- `mjx/train_rough_terrain.py`
- `mjx/tripod_controller.py`
- `mjx/view_adaptive_gait.py`
- `mjx/view_foothold_explorer.py`
- `mjx/view_foothold_planner.py`
- `mjx/view_rl_scene.py`
- `mjx/view_robot.py`
- `mjx/view_trained_policy.py`
- `mjx/wave_gait_scheduler.py`
- `scripts/build_stm32.py`
- `scripts/test_stm32_host.py`
- `scripts/train_adaptive_gait.sh`
- `scripts/view_foothold_planner.sh`
- `scripts/view_trained_policy.sh`

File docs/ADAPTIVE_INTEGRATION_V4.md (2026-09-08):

# STM32–MJX adaptive hybrid 통합 v4

## 기준과 작업 범위

브랜치: `codex/adaptive-hybrid-rl-integration`.
작업 폴더: `/home/huro/Hexapod-Robot-integration`.
main base: `de77791d6386309295be5c8d173a1f51eca99930`.
요청한 `9752c760002ac2dc7cc493ed634a881f87b7fd1e` 이후 main 변경은 URDF/mesh이며 STM32는 같다.
adaptive source: `f9d80587ff086a1f3df51b81185e742094c109c9`.
full merge 없이 main에서 시작해 root `mjx/`, 실행 wrapper 3개, 관련 문서 4개를 선택적으로 가져왔다.
HW, 기존 SW/STM32, SW/mjx 및 다른 시스템은 main을 기반으로 한다.
[수정 전 분석](ADAPTIVE_INTEGRATION_ANALYSIS.md), [전체 파일 목록](ADAPTIVE_INTEGRATION_FILES.md).

## 책임 분리

```text
LiDAR + odom/state → geometry/feasible set → PolicyAction24
                   → geometry + residual + safety projection
                   → AdaptiveExecutionPlan → STM32 contact/gait/IK/PWM
```

Geometry: terrain Z, normal/slope, coverage/confidence, edge, support extent,
IK/joint margin, path obstacle/coverage, feasible stride 및 Tripod/Wave feasibility.
RL: landing XY, clearance, roll/pitch/height, stride preference, apex/transfer timing.
Supervisor: normal Tripod → short Tripod → observed failure일 때 Wave → HOLD.
UNKNOWN은 unsafe의 증거가 아니므로 자동 Wave 전환을 허가하지 않는다.
단, 위를 보는 LiDAR가 첫 착지 영역을 못 본 상태에서 mapping과 이동이 서로 기다리는 것을 막기 위해
시작 시 6발 접촉이 확인되고 feasible Tripod landing이 아직 한 번도 만들어지지 않았을 때만 0.5 stride의
classical Tripod를 이어간다. feasible plan이 한 번 확보되면 bootstrap을 영구 종료하며 이후 UNKNOWN은
다시 HOLD한다. 영구 blind walking을 막기 위해 최대 24 phase로 제한한다. 이는 Wave 전환 근거로
쓰지 않는다. 엄격한 UNKNOWN 검사에는 viewer의
`--no-bootstrap-classical`을 사용한다.
STM32: actual transition, raw/confirmed contact, Early/Late, support recovery,
workspace/IK, joint/PWM/relay/Kill/Fault의 최종 권한.

## Policy / observation / checkpoint

`ACTION_CONTRACT=adaptive_hybrid_geometry_residual_24_v4`, ACTION_SIZE=24.
다리 순서 RF RM RB LF LM LB.

| Action | 의미 | 범위 |
|---|---|---|
| 0:12 | 6×landing XY residual | X ±0.06 m, Y ±0.04 m |
| 12:18 | 6×clearance residual | ±0.04 m |
| 18 | terrain baseline 위 roll residual | ±5° |
| 19 | terrain baseline 위 pitch residual | ±10° |
| 20 | body height offset residual | ±0.03 m, config constant |
| 21 | stride preference | 0.5–1.3, zero=1 |
| 22 | apex plateau 중심 residual | ±0.15 |
| 23 | XY transfer 중심 residual | ±0.15 |

Actor **4434-D**: proprio157 + global23 + reference54 + candidate4200.
Critic **4749-D**: actor + GT/error300 + terrain15.
Reference는 per-leg XYZ, nominal 거리, validity, dx_min/dx_max/dy_min/dy_max다.
각 축 feasible extent는 safe 후보의 extrema이며 사각형 내부가 모두 safe라는 뜻은 아니다.
기존 candidate geometry 28-feature 배열 및 robot/global 정보는 유지한다.
OBSERVATION_CONTRACT=`adaptive_hybrid_geometry_local25_extent_24_v4`.
REWARD_CONTRACT=`adaptive_hybrid_efficient_progress_v4`.

v3 및 이전 adaptive checkpoint는 contract/shape mismatch로 명시적으로 거절한다.
Stage31 18-D는 기존 controller/viewer 경로로 보존했다. v4로 자동 변환하지 않는다.
metadata에는 축별 XY limit, local offsets, timing, source SHA256 및 observation 크기를 저장한다.
현재 v4 학습 가중치는 만들지 않았다.

## Wide search와 local residual

Wide: nominal 주위 X/Y `[-8,-4,0,4,8] cm`, 25개.
Reference 선정 뒤 local: X `[-6,-3,0,3,6] cm`, Y `[-4,-2,0,2,4] cm`, 25개.
`reference + decoded XY` 요청과 가장 가까운 **safe local candidate**를 선택한다.
wide와 local은 같은 support/IK/path 검사기를 사용한다. 최종 조합 support margin도 재검사한다.
RL request가 불가능해도 검증한 neutral reference가 있으면 이를 사용한다.

Map은 64×64, 5 cm rolling grid를 유지한다. 여러 local 후보가 동일 cell의 height/confidence를
공유할 수 있지만 XY endpoint, IK, joint margin, swept path는 별도로 검사한다.
`test_real_geometry_projection_and_z_ownership`은 실제 후보 검사기를 사용하여 가능한 다리에서
selected XY가 ±6/±4 cm 끝점까지 도달함을 확인한다. 단순 decoder 상수 검사가 아니다.

Terrain Z는 query 결과다. XY를 바꾸면 다른 cell의 Z가 선택될 수 있지만 Z action은 없다.
Swing geometry는 terrain surface에서 계산하고 IK endpoint는 foot radius를 더해 변환한다.
STM32에는 policy residual을 다시 해석시키지 않고 최종 pre-posture XYZ를 보낸다.

## Clearance / 자세 / body height

```text
required = max(path_max - max(start_surface_z, landing_surface_z), 0)
h = clip(max(required + 0.06 + RL_h, required + 0.02, 0.04), 0.04, 0.18)
```

상한 때문에 `h < required+0.02`가 되면 후보를 거절한다.
Manual의 0.20 m swing 및 0.07 m radial bulge는 그대로다.
Adaptive는 검사한 start→target quintic 경로이며 fixed radial bulge를 추가하지 않는다.

Roll/pitch는 terrain normal baseline(각 ±12° 제한) + residual 후 absolute ±15°로 제한한다.
STM32 기존 posture controller가 이 absolute reference를 받는다. PI/rate/workspace는 유지한다.
Body height는 correction `body_offset_m.z`와 별도 상태다. phase target을 latch하고
0.04 m/s로 변화시키며 6발 workspace 검사를 통과한 값만 적용한다. 종료 시 memory를 재기준화한다.
Swing 중 새 plan은 active body target을 바꾸지 않는다.

## Stride / phase / trajectory

Geometry bank `[1.3,1,.75,.5,.25,.125]`에서 RL preference 이하의 가능한 값을 선택한다.
Tripod와 Wave 모두 stride preference를 적용한다. Oversize Tripod는 normal도 feasible일 때만 허가한다.

```text
Tripod T = clip(1.0 * accepted_stride, 0.5, 1.4) s
Wave   T = clip(1.0 * accepted_stride, 0.6, 1.4) s
speed_scale = accepted_stride * baseline/T * (0.2 if Wave else 1)
```

기준 시간은 둘 다1초. Accepted twist와 T를 함께 전달하므로 phase displacement는
`T*(-vx+wz*y, -vy-wz*x, -vz)`다. Wave stance는5 phase, 첫 순회 이동은 절반이다.
MJX adaptive 전후 속도 상한0.10 m/s, yaw18°/s로 main에 맞췄다. Legacy18-D 상수는 변경하지 않았다.
STM32는 pending duration을 실제 phase 진입/검증된 continuation에만 active로 복사한다.

`Q(u)=10u³−15u⁴+6u⁵`, 모든 u를[0,1]에 clip한다.
진행률p, apex A∈[.3,.7], transfer B∈[.35,.65]:

```text
qxy = Q((p-(B-.25))/.5)
qup = Q(p/(A-.2))
qdn = Q((p-(A+.2))/(.8-A))
top = max(start_z,end_z)+clearance
xy = start_xy + qxy*(end_xy-start_xy)
z = start_z + qup*(top-start_z) + qdn*(end_z-top)
```

A는 단일 최고점 시각이 아니라 폭0.4 plateau 중심이다.
Python planned_swing과 C CalculateAdaptive가 위 수식을 공유한다.
Workspace preflight와 실제 FootTrajectory는 동일 C 함수를 호출한다.
Adaptive에서는 legacy touchdown approach Z 재형성을 추가하지 않는다. 접촉 확인과
Early/Late safety 및 최종 joint/PWM 제한은 계속 적용한다.

## 실행 계획과 gait authority

`RobotAdaptiveExecutionPlan_t`: session, source observation, command sequence, plan ID,
swing mask, requested gait, execute flag, duration, absolute roll/pitch, body-height offset,
applied twist, six final XYZ/clearance/apex/transfer.

제출은 기존 RlController의 session/history/sequence/age/plan 검증을 재사용한다.
execute=false로 HOLD 또는 gait negotiation을 하고 새 광고 계획을 기다린다.
requested gait가 달라도 mid-swing actual gait는 바뀌지 않는다. 모두 접촉한 경계에서 새 패턴의
preview를 발행하고, 해당 실행 plan이 workspace 검사를 통과해야 actual pattern을 바꾸고 이륙한다.
FootTrajectory pending→active 복사는 swing entry 한 번이다. 새 action/map/timing이 active를 덮지 않는다.

Wave order 0,5,1,3,2,4. MJX의 raw/confirmed contact는 simulation input으로 구현한 근사다.
STM32의 1-ms FSR 샘플링을 그대로 재현했다고 보지 않는다. Late .12 m/s, inward .096 m/s,
한계10 cm이며 support loss는 회복/정지로 처리한다. Wave common-Z recovery는 비활성이다.
Adaptive Tripod common-Z도 geometry Z와 별도 누적 이동이 충돌하지 않도록 적용하지 않는다.

## Jetson / SPI

[128-byte v3 명세](ADAPTIVE_SPI_V3.md). C/Python explicit offset·fixed point·CRC codec을 추가했다.
STM32 DMA→main-loop decode→app submit 경로에 연결했다. 실제 SPI 전기적 동작은 미검증이다.
두 observation page를 같은 capture로 묶고 receiver는 session/sequence/plan 일치를 확인한다.

`SW/Jetson/adaptive_runtime.py`는 coherent observation + 외부 state estimate + deskew/self-filter된
world LiDAR returns를 받아 동일 JAX geometry와 supervisor를 사용한다. zero-action 지원.
Odometry 회전은 hardware forward/left/up→world, position/CoM은 동일 world frame이다.
Map timestamp와 now는 같은 monotonic clock을 사용한다.

**Live Livox/odom 수집, 시간 동기화, SPI master/DRDY 이벤트 루프는 배치 환경 연결 작업으로 남아 있다.**
Nonzero policy 사용 시 완전한4434-D actor vector를 caller가 제공해야 한다. 현재 SPI 관측만으로
odom velocity, slip/history 등을 임의로0으로 채우지 않는다. 따라서 지금은 보드에 바로 연결해
학습 policy를 운용하는 완성된 Jetson 서비스라고 주장하지 않는다.

## 최소 확인 결과와 사용자 확인 범위

실행: 기존 MJX hybrid9 + v4 5 = **14 tests PASS**.
새 검사는 실제 local geometry endpoint 사용, Z ownership, Python/C32개 golden trajectory,
C SPI 디코딩/CRC/중복/timeout, baseline timing 및 boundary duration/gait transition을 포함한다.
STM32 native portable11개 **PASS**: calibration conversion, user command, kinematics, controller,
workspace, gait, mode transition, safety, communication, RL input, RL stop.
핵심 C module와 app/SPI는 native syntax 검사 통과. Python syntax 검사 및 diff whitespace 검사 통과.

Native compiler는 기존 controller/mode-transition test의 array-size 추론 warning을 출력했다.
CUDA 장치가 없는 sandbox에서 JAX CUDA plugin 초기화 경고가 있었지만 CPU14개 검사는 통과했다.
Native HAL I/O stub은 호출되면 abort하므로 board 동작을 성공으로 위장하지 않는다.
ARM ELF build, 실제 DMA/DRDY, 전체 viewer rollout, Stage0 metric, PPO, 실제 로봇은 실행하지 않았다.
새 portable ARM build script는 추가한 C source도 포함하며 **미실행**이다.

남은 위험: foot-centre/실제 발 접촉점·servo model 보정, phase-entry frame과 움직이는 몸체의 오차,
posture PI/필터 및 raw-touchdown 취소 후 재개 궤적의 sim/hardware 차이, fixed-sample path 검사 사이 충돌,
발 이외 몸체 충돌, state-estimation/deskew/clock/latency, LiDAR coverage, quantization,
60-ms 관측 lease 안의 planner latency. 긴 계산은 HOLD/timeout으로 나타나야 하며 lease를 임의로 늘리지 않는다.
현재 height map 누적 max/min은 동적 지형 및 odom drift에 대한 별도 평가가 필요하다.
이 결과는 계단 등판 성공·학습 성공·실기 검증 완료를 의미하지 않는다.

## 사용자 실행 순서

```bash
cd /home/huro/Hexapod-Robot-integration
source /home/huro/.venvs/hexapod-mjx/bin/activate

# 1. Stage 0: 반드시 가중치 없이 확인
bash scripts/view_foothold_planner.sh --controller adaptive --terrain flat --perception oracle
bash scripts/view_foothold_planner.sh --controller adaptive --terrain steps --perception oracle
bash scripts/view_foothold_planner.sh --controller adaptive --terrain steps --perception lidar --stage0

# 2. 필요 시 계약 검사 재현
JAX_PLATFORMS=cpu python -m unittest mjx.tests.test_adaptive_hybrid mjx.tests.test_adaptive_v4
python3 scripts/test_stm32_host.py

# 3. Offline synthetic point-cloud → zero-action → 128-byte file (전송 없음)
python SW/Jetson/make_offline_fixture.py --output /tmp/hexapod-flat-input.npz
python SW/Jetson/adaptive_runtime.py --input /tmp/hexapod-flat-input.npz --output /tmp/hexapod-command.bin

# 4. ARM GCC 설치/경로 설정 후, flash 없이 ELF만 생성
python3 scripts/build_stm32.py --compiler arm-none-eabi-gcc

# 5. Stage 0 통과 후에만 새 v4 학습
bash scripts/train_adaptive_gait.sh --stage 1 --terrain-level 0 --perception lidar --num-envs 64
# 다음 curriculum에서 --terrain-level 3, 5 등을 적용; Stage 2 Wave / Stage 3 hybrid
```

Viewer에서는 nominal(연보라), wide reference(흰색), RL request(청록), local candidate 상태색,
projected(주황), latched execution(진빨강)을 비교한다. 방향키 연속 보행/정지 및 G FOV 토글은
[viewer 사용법](HEXAPOD_MJX_ADAPTIVE_GAIT_USAGE.md)을 참고한다.
Flat normal Tripod → 계단 short-step → observed Tripod 실패 시 Wave → 평탄화 복귀 → unknown/HOLD 순으로
확인한다. oracle에서도 landing이 없으면 planner/IK/path, oracle만 되면 LiDAR/map filter부터 확인한다.

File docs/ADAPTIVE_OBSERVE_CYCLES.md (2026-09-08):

# 짧은 학습 cycle과 W&B

`--profile observe`는 같은 평지 Tripod를 지정한 횟수만큼 반복한다.
기존 `fast`는 16개 지형/gait stage의 승급 커리큘럼이므로 다른 용도다.
observe에서는 승급 성공률 때문에 3회 시도 뒤 중단되지 않는다.
실제 학습 오류·영상 저장 실패는 로그를 남기고 중단한다.

```bash
cd /home/huro/Hexapod-Robot-integration
source /home/huro/.venvs/hexapod-mjx/bin/activate
bash scripts/train_adaptive_curriculum.sh \
  --profile observe --cycles 5 \
  --perception teacher --run-name adaptive-observe-cycles \
  --timesteps-per-stage 400000 \
  --num-envs 128 --batch-size 64 --num-minibatches 4 \
  --num-evals 5 --num-eval-envs 4 \
  --episode-length 800 --action-profile flat_safe \
  --best-video-duration 12 --wandb --wandb-mode online
```

- 한 cycle: 약 400k 환경 step. PPO batch 배수로 올림될 수 있다.
- 평가: 초기 1회 + 학습 중 4회. `num-evals 4`는 학습 중 3회였음.
- 800 policy step은 최대 16초 episode. 조기 실패 또는 목표 도달 시 먼저 종료한다.
- cycle별 최고 score는 `eval/episode_reward` 기준이다. 초기 미학습 평가는 best에서 제외한다.
- 매 평가 callback에서 `cycle/best_score`, `cycle/best_step`과 summary를 W&B에 기록한다.
  실시간은 평가 결과가 나올 때의 업로드를 뜻하며 매 물리 tick의 평가를 뜻하지 않는다.
- cycle 종료 직후 `cycle/best_video`를 같은 run에 업로드한다. 최대 12초 GIF이며
  성공·실패로 일찍 끝나면 `.termination.json`에 이유를 남긴다.
- artifact에는 GIF, 실제 best checkpoint 디렉터리, metrics, best pointer,
  영상 종료 보고서를 포함한다. 별도의 전체 최고 선정은 없다.
- 모든 cycle은 같은 W&B group 아래 별도 run이고 seed도 고정해 비교한다.
- 다음 cycle은 직전 cycle의 best 가중치와 관측 정규화를 복원한다.
  PPO optimizer 상태까지 연속 유지하는 방식은 아니며 subprocess마다 재초기화된다.
- 같은 run-name으로 다시 실행하면 기존 결과를 보존하고 timestamp를 붙인 새 실험을 만든다.

저장 루트: `mjx/runs/adaptive-curriculum/<실험명>/`.
각 `00_tripod-flat_try00/` 등의 디렉터리에 `videos/best.gif`, checkpoints, monitor 파일이 있다.
상위 `cycle-00-try00.log`에는 학습·렌더링 오류를 포함한 표준 출력을 저장하며,
`active_cycle.json`에는 마지막 실행 명령을 기록한다.

400k step은 비교를 위한 시작 설정이며 유의미한 개선을 보장하는 최소 학습량은 아니다.
W&B 인증은 현재 머신의 로그인 계정을 사용한다. 이전 소스 checkpoint의 strict hash
검사를 우회하지 않는다. 이번 변경의 학습·시뮬레이션·렌더링·업로드는 실행하지 않았다.

## 명령어 조절표

아래 표는 **curriculum wrapper** `scripts/train_adaptive_curriculum.sh`에서 지원하는 옵션이다.
명령 마지막의 `\`는 다음 줄도 같은 명령이라는 뜻이며, 마지막 옵션 뒤에는 붙이지 않는다.
변경하려는 옵션의 숫자나 값을 바꾸면 된다.

| 조절 목적 | 옵션 | 기본값 | 사용 예시 / 영향 |
|---|---|---|---|
| 같은 평지에서 반복 | `--profile` | `fast` | 반복 관찰은 반드시 `observe`; `fast`/`full`은 지형 승급 |
| 반복 횟수 | `--cycles` | `5` | `observe` 전용. `3`이면 세 cycle, `10`이면 열 cycle |
| cycle 하나의 학습량 | `--timesteps-per-stage` | `10000000` | `400000`에서 시작. `800000`이면 cycle당 학습량 두 배 |
| 동시에 학습하는 환경 수 | `--num-envs` | `64` | 예시 `128`. 늘리면 메모리도 증가하며 속도 개선은 하드웨어에 따라 다름 |
| PPO minibatch 크기 | `--batch-size` | `64` | 환경 수와 다른 의미. 기본 유지 권장 |
| PPO minibatch 개수 | `--num-minibatches` | `4` | `batch-size × num-minibatches`가 `num-envs`로 나누어떨어져야 함 |
| 평가·checkpoint 빈도 | `--num-evals` | `10` | `5` = 초기 1회 + 학습 중 4회. 늘리면 score 갱신이 잦아지지만 평가 비용 증가 |
| 한 번에 평가하는 환경 수 | `--num-eval-envs` | `4` | 실제로는 `min(num-envs, num-eval-envs)`. `8`이면 평가 표본을 늘림 |
| episode 최대 길이 | `--episode-length` | `2000` | 정책 step 단위. `800` = 16초, `1000` = 20초. 실제 대기 시간이 아님 |
| RL 조절 권한 | `--action-profile` | `full` | 평지 초기에는 `flat_safe`; 아래 표 참고 |
| 영상 최대 길이 | `--best-video-duration` | `12` | 초 단위. `20`으로 늘려도 학습량은 같고 렌더링 비용만 증가 |
| 센서 입력 종류 | `--perception` | `teacher` | `teacher` = GT 지형, `lidar` = LiDAR map. teacher 결과를 LiDAR 성공으로 해석하지 않음 |
| 비교 seed | `--seed` | `40` | observe는 cycle마다 같은 seed; 실험 간 seed를 바꾸어 비교 가능 |
| 실험 이름 / W&B group | `--run-name` | `adaptive-v4-curriculum` | 예: `flat-400k-5cycles`. 같은 이름 재사용 시 timestamp 자동 추가 |
| 로컬 결과 상위 경로 | `--run-root` | `mjx/runs/adaptive-curriculum` | 예: `--run-root /home/huro/hexapod-runs` |
| 기존 가중치에서 시작 | `--restore` | 없음 | 호환되는 checkpoint 또는 run 경로. 기존 결과를 덮어쓰는 resume은 아님 |
| teacher로 LiDAR 초기화 | `--init-teacher` | 없음 | `--perception lidar`에서만 사용. `--restore`와 동시 사용 불가 |
| W&B 연결 | `--wandb` | 켜짐 | 명령에 명시해 두면 연결 의도가 분명함. `--no-wandb`는 명시적 비활성 |
| W&B project | `--wandb-project` | `hexapod-adaptive-gait` | 원하는 project 이름 |
| W&B 계정/팀 | `--wandb-entity` | 현재 로그인 기본값 | 원하는 사용자명 또는 팀 이름 |
| W&B 전송 모드 | `--wandb-mode` | `online` | 실시간 업로드는 `online`. `offline`/`disabled`는 실시간 업로드하지 않음 |
| 시작 stage 인덱스 | `--start-index` | `0` | observe도 해당 인덱스부터 마지막까지 실행. 이전 가중치는 자동 탐색하지 않으므로 `--restore` 필요 |
| 지형 승급 지표 | `--promote-key` | `eval/episode_terrain_success` | `fast`/`full` 전용; cycle best 선정 지표와 다름 |
| 승급 기준 | `--promote-threshold` | `0.70` | `fast`/`full` 전용, 범위 0~1 |
| 승급 실패 추가 시도 | `--max-retries` | `2` | `fast`/`full`: 최초+추가 2회. observe는 승급 검사 없이 다음 cycle |
| 재시도 소진 시 동작 | `--on-stage-failure` | `stop` | `advance`는 마지막 시도의 best 가중치로 다음 stage 진행. 승급 성공으로 기록하지 않음 |

`--cycles`는 보행의 Tripod cycle 수가 아니라 **학습 실행 구간 수**다.
총 요청 학습량은 observe에서 `cycles × timesteps-per-stage`이고, 병렬 환경 수를 다시 곱하지 않는다.
예시 5 × 400000 = 200만 환경 step이며, 평가·영상 생성 step은 별도다.
`num-evals 5`의 평가 간격은 약 `timesteps-per-stage / 4`이며 batch 단위 올림 때문에 정확히 100000마다일 필요는 없다.
`num-evals 1`도 구현상 학습 후 평가 1회를 수행한다.

## RL 권한 조절

| profile | landing XY / clearance action 배율 | body / stride / timing action 배율 |
|---|---|---|
| `flat_safe` | 0.10 | 0 (classical baseline) |
| `terrain_mid` | 0.50 | 0.35 |
| `terrain_high` | 0.75 | 0.65 |
| `full` | 1.00 | 1.00 |

배율은 policy 출력에 적용되며 geometry/safety projection을 통과한 값만 실행한다.
작은 XY 요청은 local candidate 격자에 투영되면서 reference와 동일한 착지점이 될 수 있다.
`flat_safe`를 전체 험지 커리큘럼에 고정하면 자세·보폭·timing을 학습할 수 없다.
observe에서 평지 기본 보행을 먼저 비교하고, 지형 적응 학습으로 넘어갈 때 profile을 선택한다.

## 자주 바꾸는 조합

기본 명령에서 다음 옵션만 교체한다. 같은 옵션을 여러 번 적기보다 기존 값을 바꾼다.

| 원하는 실험 | 바꿀 옵션 |
|---|---|
| 짧게 세 구간만 비교 | `--cycles 3 --timesteps-per-stage 400000` |
| 한 구간을 더 충분히 학습 | `--cycles 5 --timesteps-per-stage 800000` |
| score를 더 자주 확인 | `--num-evals 9` (초기+학습 중 8회) |
| 평가 표본을 더 확보 | `--num-eval-envs 8` |
| GPU 메모리 부담 완화 시도 | `--num-envs 64 --batch-size 64 --num-minibatches 4` |
| 긴 보행과 영상 비교 | `--episode-length 1500 --best-video-duration 25` |
| 다른 실험과 분리 | `--run-name flat-800k-seed41 --seed 41` |

episode/영상 길이를 늘려도 성공·실패의 조기 종료 조건은 유지된다.
짧은 실행이라도 최초 JAX 컴파일과 cycle 종료 렌더링 시간이 필요하다. 일정한 분 단위 완료 시간을 보장하지 않는다.

## 가중치 이어받기

각 cycle의 `monitor/best_checkpoint.json`에 best checkpoint 경로가 기록된다.
그 경로를 `--restore`에 지정하고 새 실험명으로 시작한다. run 디렉터리를 지정하면
그 안의 **가장 최근** checkpoint가 선택되므로, best를 원할 때는 JSON의 정확한 경로를 쓴다.

```bash
# 기존 기본 명령에 다음 두 옵션을 지정한다.
--run-name adaptive-observe-next
--restore /실제/경로/checkpoints/000000000000
```

위 경로는 예시 자리표시자다. metadata에 기록된 실제 경로로 교체한다.
같은 소스 계약만 복원 가능하며 소스가 바뀌었다는 오류를 무시하거나 hash를 수정하지 않는다.
가중치와 관측 정규화만 복원하고 optimizer는 새로 시작한다.

## W&B에서 보는 항목과 영상 저장 시점

| 시점 | 항목 |
|---|---|
| 매 평가 완료 | `eval/*`, `training/*`, 현재 cycle의 `cycle/best_score`, `cycle/best_step` |
| cycle 완료 | 해당 cycle best의 `cycle/best_video` 및 policy artifact |
| 오류 발생 | 로컬 `cycle-NN-tryNN.log`, 렌더링 실패 시 cycle 내부 `monitor/best_video_error.json` |

score는 cycle별 summary에도 기록되므로 run 목록에서 비교할 수 있다.
영상은 평가마다 생성하지 않고 cycle 종료 직후 한 번 생성·업로드한다.
W&B의 네트워크 전송 시간은 별도로 걸릴 수 있다. 전체 best를 선별하거나 합치는 코드는 없다.

## 추가 학습 옵션이 필요할 때

한 구간용 `scripts/train_adaptive_gait.sh`에는 `--learning-rate`, `--entropy-cost`,
`--score-key`, `--video-fps`, `--video-width`, `--video-height`, LiDAR sampling 옵션이 있다.
이 옵션은 현재 curriculum wrapper가 전달하지 않으므로 wrapper 명령에 바로 붙이면 안 된다.
전체 옵션 설명만 출력하는 명령은 다음과 같다. 학습을 시작하지 않는다.

```bash
bash scripts/train_adaptive_curriculum.sh --help
bash scripts/train_adaptive_gait.sh --help
```

공식 반복 학습 진입점은 `train_adaptive_curriculum.sh`다.
이름이 비슷한 `mjx/train_adoptive_curriculum.py`는 기존 별도 파일이며 위 명령에서 사용하지 않는다.

## 성공률 미달로 종료됐을 때

`--max-retries 3`은 최초 1회+추가 3회이며, 총 4회 시도 뒤 성공률이
`--promote-threshold 0.70` 미만이면 기본 동작은 중단이다. reward best는
승급 성공률 best와 다르다. W&B 업로드 오류나 checkpoint 유실을 의미하지 않는다.

중단 정보는 `failed_stage.json`에 checkpoint·다음 stage index와 함께 저장된다.
사용자가 기준 미달이어도 다음 지형으로 진행하려면 `--start-index 1`과
해당 checkpoint의 `--restore`를 지정한다. 이후에도 재시도 소진 시 계속하려면
`--on-stage-failure advance`를 추가한다. 이 옵션은 LiDAR/planner HOLD 문제를
고치는 것이 아니라 curriculum 운영 동작만 변경한다. low-level safety는 유지된다.
`curriculum_state.json`의 `promotion_passed`와 `advanced_without_passing`으로
실제 승급과 기준 미달 진행을 구분한다. 마지막 시도의 best를 사용하며
서로 다른 seed의 과거 retry 점수를 단순 비교해 전체 best로 선정하지 않는다.

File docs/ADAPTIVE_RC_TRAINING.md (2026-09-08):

# 조종기 명령을 전제로 하는 학습

이 문서는 선택 가능한 RC 모드의 참고 자료다. 현재 기본 방향은 [yaw 명령 없는 전진 완주](ADAPTIVE_GT_TEACHER.md)다.

## 구현 범위

상위 입력은 `[vx, wz]`이고 다리/관절 실행은 위치 기반이다. RC 모드는
전진·후진·제자리 좌/우 회전·전후진 곡선·정지 명령을 입력받는 residual policy를 학습한다.
학습 중 물리 조종기를 연결하는 대신 JAX fixed-shape sampler로 조작 명령을 생성한다.
실제 RC 수신기/Jetson/STM32 통신 연결을 추가한 작업은 아니다.

`--command-mode terrain`은 기존 전진 등판 task, `--command-mode rc`는 자유 조종 추종 task다.
작업 구분은 checkpoint metadata에 저장하며 다른 task의 가중치를 자동 restore하지 않는다.
24-D action과 CNN 관측 크기, terrain_mid residual 권한은 유지한다. 과거 source-hash
계약의 checkpoint는 이전 코드에서 재생해야 한다. 이미 실행 중인 PPO를 자동 변경하지 않는다.
이 변경의 학습·rollout·unit test는 실행하지 않았다.

## 조종 명령과 목표

각 목표 명령은 2~5초 유지한다. vx는 ±0.03~0.08m/s, yaw는 ±0.12~0.25rad/s,
정지/전진/후진/제자리 좌회전/우회전/네 방향 전후진 곡선을 균등한 9개 mode로 뽑는다.
slew 한계는 vx 0.08m/s², yaw 0.4rad/s²이며 deadband는 0.005m/s, 0.02rad/s다.
deadband 이전의 별도 slew 상태를 저장하여 작은 tick마다 0으로 되돌아가는 오류를 피한다.
지형/물리 외란 RNG와 명령 RNG를 분리하여 paired baseline/policy의 명령 sequence가 같도록 한다.

현재 action을 계산한 뒤 command를 몰래 바꾸지 않는다. step 종료에 **다음 observation의
command를 갱신**해 다음 policy tick에서 그대로 사용한다. 초기 command delay 동안 0이다.
Viewer는 checkpoint의 task를 따르되 `external_commands=True`로 자동 sampler를 끈다.
그때는 기존 방향키/WASD가 명령을 공급한다. 실물 조종기 입력은 같은 command 경로로
연결해야 하며 실제 전처리 deadband/slew와 학습 설정의 일치는 후속 검증 대상이다.

## 보상과 실패 기준

- velocity reward는 요청한 **부호 있는 vx**와 실제 body-forward 속도를 비교한다.
- progress/under-speed는 `[vx, 0.3*wz]` 공간의 명령 방향 투영으로 계산한다.
  yaw를 선형 속도로 비교하는 0.3m는 reward/watchdog용 characteristic radius이며 실측 몸체 치수가 아니다.
- 후진·제자리 회전이 world X 증가 없음 때문에 no-progress로 종료되지 않는다.
- 완전 정지 명령에는 no-progress watchdog을 비활성화한다. 정지 상태에서 움직이지 않는 것은 정상이다.
- RC에서는 고정 world-X goal 및 상승 보너스를 사용하지 않는다. 안전하게 episode horizon을
  마치고, 명령 활성 시간의 70% 이상에서 선형 오차 ≤0.02m/s 및 yaw 오차 ≤0.07rad/s이면
  `command_success=1`이다. 전환 중 추종 오차도 포함한다. 정지로 저속 명령을 통과할 수
  없도록 최소 목표 속도보다 작은 오차 문턱을 사용한다.
- 안전 실패와 3초 no-progress는 계속 종료하며, 미달한 horizon 종료는 timeout이다.
  adaptive 완주/실패 reward 크기는 유지하되 RC의 +120은 command task 성공 의미다.
- `terrain_success`는 RC에서 0이다. RC 성공을 계단 등판 성공이라고 기록하지 않는다.

`command_success`의 70% 시간 기준과 curriculum 승급의 70% episode 성공률은 서로 다른 조건이다.
16 eval env 중 최소 12개(75%)가 command task에 성공해야 기본 승급 문턱 70%를 넘는다.
작은 표본 및 랜덤 명령이므로 실기 조종 성능을 보장하는 기준은 아니다.

## 먼저 평지 RC 학습

자유 회전/후진을 좁은 일방향 stair course에 그대로 넣으면 계단 밖으로 돌아가는 정상 명령과
등판 목표가 충돌한다. 따라서 `--profile rc`는 평지 Tripod → 평지 Wave → 평지 Hybrid다.
무한 retry는 명령 성공률을 기준으로 한다. 거친 지형에서의 조종+등판 혼합 task는 아직
구현하지 않았으며, 이후 command-conditioned terrain course/명령 분포를 함께 설계해야 한다.

```bash
cd /home/huro/Hexapod-Robot-integration
source /home/huro/.venvs/hexapod-mjx/bin/activate
bash scripts/train_adaptive_curriculum.sh \
  --profile rc --command-mode rc --perception teacher \
  --run-name adaptive-rc-gt-flat \
  --timesteps-per-stage 800000 \
  --num-envs 512 --batch-size 128 --num-minibatches 4 \
  --num-evals 5 --num-eval-envs 16 --episode-length 2000 \
  --action-profile terrain_mid --discounting .997 \
  --baseline-comparison-seconds 20 --best-video-duration 40 \
  --promote-key eval/episode_command_success --promote-threshold .70 \
  --max-retries -1 --on-stage-failure stop \
  --wandb --wandb-mode online
```

새 task이므로 위 명령은 restore 없이 시작한다. `--episode-length 2000`은 40초로
여러 명령 전환을 포함한다. 기존 계단 학습 run/checkpoint를 삭제하지 않는다.

### 학습 중 코드 변경과 retry

`scripts/train_adaptive_curriculum.sh`는 시작 시 현재 commit을 별도 detached
worktree(`~/.cache/hexapod-training-sources/`)에 고정한다. 같은 run의 모든 retry와
다음 stage는 그 소스로 실행되므로 개발 저장소 수정이 중간 retry에 섞이지 않는다.
시작 로그의 `PINNED SOURCE`와 `SOURCE REVISION`을 보관한다. 실행 중 해당
worktree를 수정/삭제하지 않는다. 저장 위치는 기존 `mjx/runs/adaptive-curriculum`이다.
추적 파일에 미커밋 변경이 있으면 시작 전에 오류를 내므로 변경을 commit한 뒤 실행한다.
untracked 파일은 복사되지 않는다. 모델/소스 의존 파일도 commit되어 있어야 한다.

직접 `python mjx/train_adaptive_curriculum.py`나 `train_adaptive_gait.py`를 실행하면
이 고정 기능이 적용되지 않는다. 이미 실행 중인 run에는 소급 적용되지 않는다.
체크포인트 source hash 검증은 유지한다. 과거 계단 checkpoint를 새 RC task로
자동 변환하지 않으며, 이번 RC 학습의 **첫 실행에는 `--restore`를 넣지 않는다.**
이후 동일 RC run 내 retry/승급에서는 manager가 직전 checkpoint를 이어받는 것이 정상이다.
학습·영상 생성·시뮬레이션 검증은 사용자가 실행한다.

## 기록

- cycle best는 `command_success` 우선, 같은 성공률이면 reward로 선택한다.
- W&B cycle별 best score/영상/40초 최대 길이 및 정지 직전 진단은 유지한다.
- 영상 상단에 command task, vx, yaw를 표시한다. 정지 명령 구간과 제어기 정지를 구분할 수 있다.
- `eval/episode_command_success`는 episode 성공 비율이다.
- `command/linear_error_mps`, `command/yaw_error_radps`, `command/vx`, `command/wz`는
  per-tick 지표다. Brax episode 값은 합산되므로 평균을 보려면 episode length로 나눈다.
- `command_good_fraction`은 매 tick의 누적 good fraction이다. episode 합을 그대로 성공률로
  해석하지 않는다. 비교 진단의 linear/yaw error는 실제 실행 tick수로 나눈 평균이다.
- RC 비교의 `forward_m`는 출발 방향 순변위로, 후진/회전을 포함한 policy의 우열 지표가 아니다.
  `comparison/*/command/linear_error_mps`, `comparison/*/command/yaw_error_radps`를 우선 본다.

사용자용 단위 검사: `python -m unittest mjx.tests.test_operator_commands`.
부호 있는 후진/yaw/정지 보상, 정지로 저속 명령 통과 방지, deadband에서의 slew 탈출,
fixed-size batched sampler를 검사한다. 이번 작업에서는 실행하지 않았다.

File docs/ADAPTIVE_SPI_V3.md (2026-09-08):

# Adaptive SPI v3 — 128-byte explicit wire contract

Policy contract is **24-D v4**; transport version is **SPI v3**. They are different versions.
All integers are little endian. Signed fields are two's complement. CRC-16/CCITT-FALSE:
polynomial 0x1021, initial 0xffff, no reflection, no xorout; CRC covers bytes 0–125.
SPI mode 0, MSB-first, DRDY/DMA authority remains STM32. Each transaction is 128 bytes.
The app defaults to the existing 64-byte sensor/GPS transport. The 128-byte adaptive
transport remains available through an explicit `JetsonSpi_EnableV3` call after
initialization; the Jetson master must use the matching transport. GPS is not included
in the adaptive observation pages below. No automatic frame-length negotiation.

## Command (0x32)

| Offset | Bytes | Meaning / scale |
|---|---:|---|
| 0 | 1 | 0xa5 |
| 1 | 1 | 0x32: version 3, command type 2 |
| 2 | 2 | execution sequence u16 |
| 4 | 1 | bit0 execute; other bits zero |
| 5 | 1 | action/execution semantic version 4 |
| 6 | 4 | nonzero session u32 |
| 10 | 2 | source observation sequence u16 |
| 12 | 2 | advertised plan ID u16 |
| 14 | 1 | advertised swing mask, RF RM RB LF LM LB |
| 15 | 1 | requested gait: Tripod 0, Wave 1 |
| 16 | 2 | phase duration u16 milliseconds |
| 18,20 | 2 each | absolute roll/pitch i16 × 0.0001 rad |
| 22 | 2 | body height offset i16 millimetres |
| 24,26,28,30 | 2 each | applied vx,vy,vz,wz i16 × 0.0001 SI; vz=0 |
| 32+12i | 6 | final leg XYZ, three i16 millimetres |
| 38+12i | 2 | clearance u16 millimetres |
| 40+12i,42+12i | 2 each | apex/transfer u16 × 0.0001 |
| 104–125 | 22 | zero reserved |
| 126 | 2 | CRC |

Final XYZ uses the **phase-entry, pre-posture controller frame**, x forward/y left/z up.
It is an IK endpoint, including the simulator's 32-mm foot-centre convention after terrain
height conversion. It is not the policy XY residual or odom XYZ. Hardware foot geometry
must be calibrated before deployment. No landing-Z policy channel exists.

execute=0 is a validated HOLD/gait negotiation message: it can keep the command lease alive
but never permits lift. It still references the advertised old plan/mask. STM32 requests a
new gait preview at an all-contact boundary, validates the new execution plan, then changes
the active pattern on launch. Jetson must wait for the new advertised pattern/mask/plan ID.
Duplicate or old sequence, wrong session/plan, stale observation and invalid values do not
refresh the command lease. All-zero receive bytes are a read-only NOP, not a heartbeat.

## Observation state (0x31)

Bytes 0–15 share the command header, except sequence/source both name the capture and byte15
is actual gait. Flags: bit0 valid plan, bit1 leg ACK valid, bit2 startup, bit3 gait enabled.

| Offset | Content |
|---|---|
| 16 | elapsed phase milliseconds i16 |
| 18–23 | IMU roll/pitch/yaw i16 × 0.0001 rad |
| 24–29 | processed command vx/vy/wz i16 × 0.0001 |
| 30–37 | applied vx/vy/vz/wz i16 × 0.0001 |
| 38,39 | confirmed/raw contact masks |
| 40,41 | RL state, flags |
| 42,44 | execution ACK sequence, plan ID u16 |
| 46,47 | ACK mask, phase index modulo 6 |
| 48–83 | 18 measured joint angles i16 × 0.0001 rad, controller order/signs |
| 84–119 | six nominal XYZ triples i16 millimetres |
| 120,122 | active duration ms, applied body height mm |
| 124,125 | submit result enum, **advertised plan gait** |
| 126–127 | CRC |

## Observation detail (0x35)

Same header/session/sequence/plan/mask/flags as its state page. Bytes16–51: six start XYZ;
52–87: six current pre-height foot-memory XYZ, all i16 millimetres. Bytes88–93: six main
leg-state enums. Bytes94–99: applied posture-command roll/pitch/yaw i16 × 0.0001 rad.
Bytes100–103: original STM32 capture timestamp milliseconds u32. Bytes104–125 reserved zero.
CRC remains126. Both pages come from one stored snapshot, not consecutive control ticks.

The receiver assembles only matching pages. Reading the second page does not refresh the
original timestamp. Observation lease remains60 ms; execution lease100 ms. Measure end-to-end
latency and map/odom clock synchronization before live operation. Two pages require two
transactions; this is not a claim of 200-Hz neural inference.

C encoding uses explicit offsets and scales; struct assignment is internal only. DMA buffers
hold encoded bytes. ISR completion handling only flags a finished transfer; parsing and app
submission run in the main loop. Observation values saturate to wire ranges; command
serialization validates inputs and angular quantization rounds toward zero.

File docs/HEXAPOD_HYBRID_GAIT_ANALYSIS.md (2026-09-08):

> 이 문서는 이전 개발 단계의 설계/사용 이력을 포함합니다. 현재 v4 contract, timing, 실행 경로는 [통합 문서](ADAPTIVE_INTEGRATION_V4.md)를 따릅니다.

# 구현 전 분석: LiDAR foothold / Tripod–Wave supervisor

기준: 작업 브랜치 `3c8f528`, 원격 main `90a8950` (2026-09-06 fetch).
분석을 사용자에게 먼저 보고한 뒤 구현한다. 이전 요청으로 진행 중이던 25개 후보/oracle 변경은
미커밋 초안이었으며 실행 검증하지 않았다. GUI/보행/PPO 검증은 사용자에게 맡긴다.

## 기존 데이터 흐름과 gate

JAX MID-360 ray → 64×64/5 cm/60초 지도 → nominal 주변 3×3/±4 cm 후보 →
중심+네 이웃 all-known → spread 2.5 cm → XY 요청과 가까운 후보 → terrain Z+
32 mm 발 반지름 → clearance → tripod swing 경계 latch → posture/contact/IK.

후보가 사라질 수 있는 지점은 FOV·가림·dropout·지도 범위·age·중심/주변 관측·spread·
검색 범위·경로 IK·clearance·tripod 전체 거부·정지/스윙 경계 대기다.
점군만 보고 실제 원인을 확정할 수 없다. 기존 selected 이전 탈락 진단이 없어 원인 분리가 어려웠다.
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

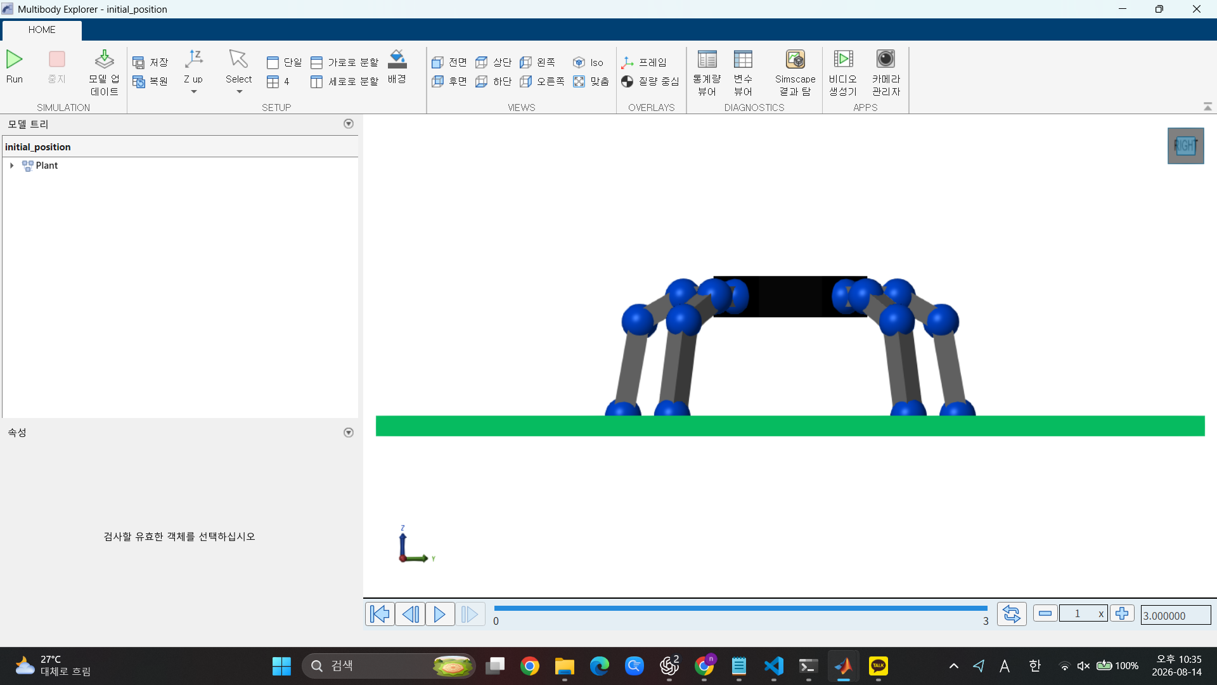
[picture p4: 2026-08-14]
SW/Controller/좌표축/초기 자세 정면.png

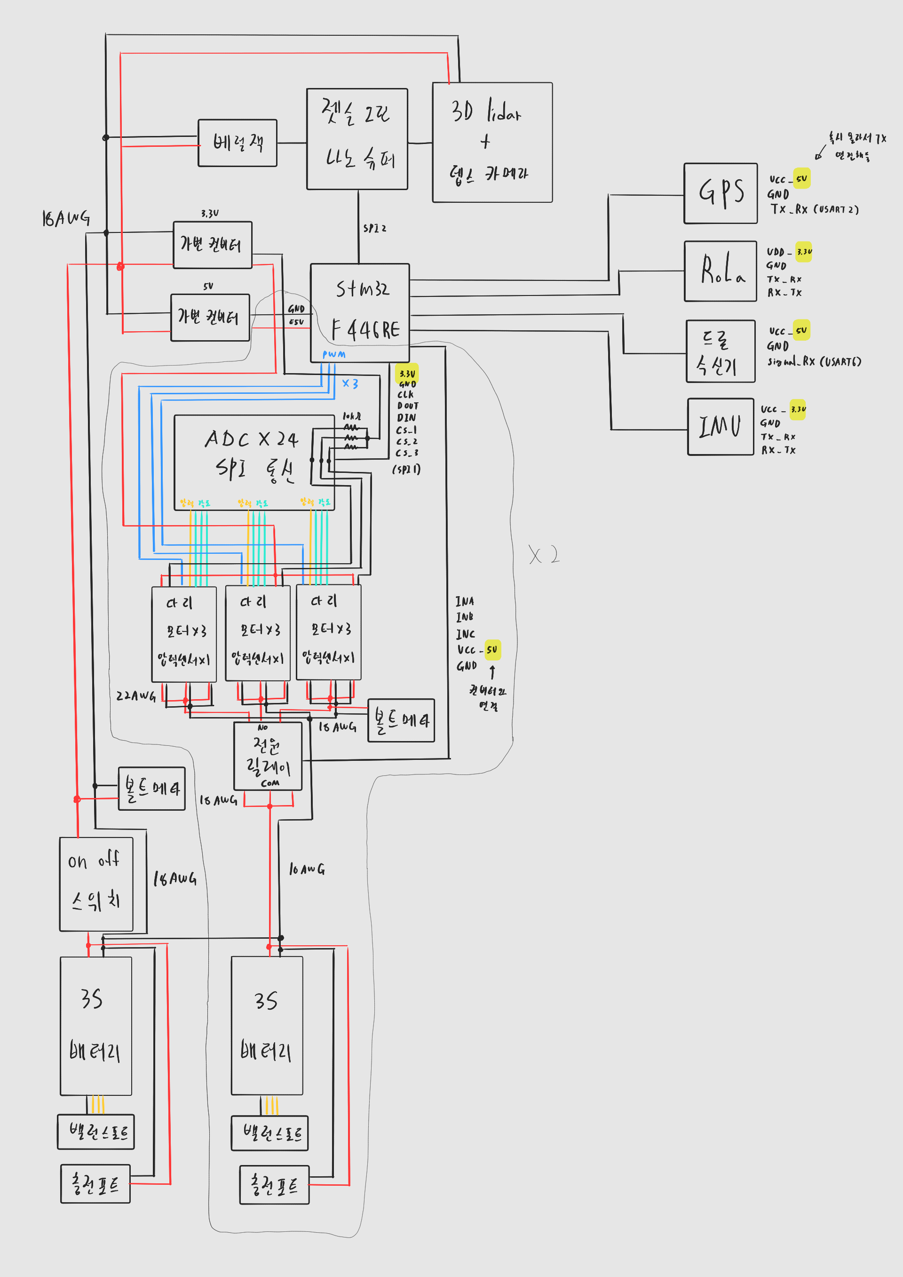
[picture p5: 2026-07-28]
HW/6족배선.png

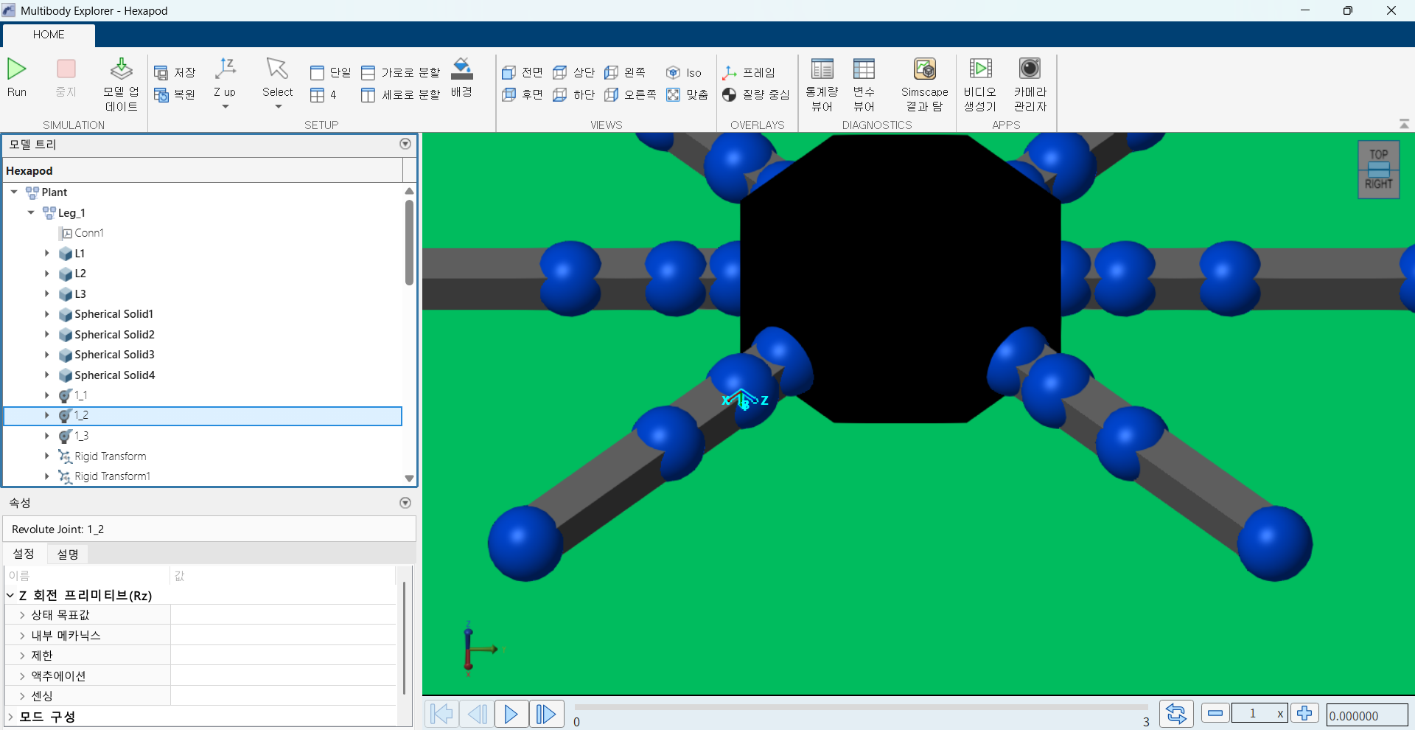
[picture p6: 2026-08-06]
SW/Controller/좌표축/오른쪽 2번 관절 좌표축.png

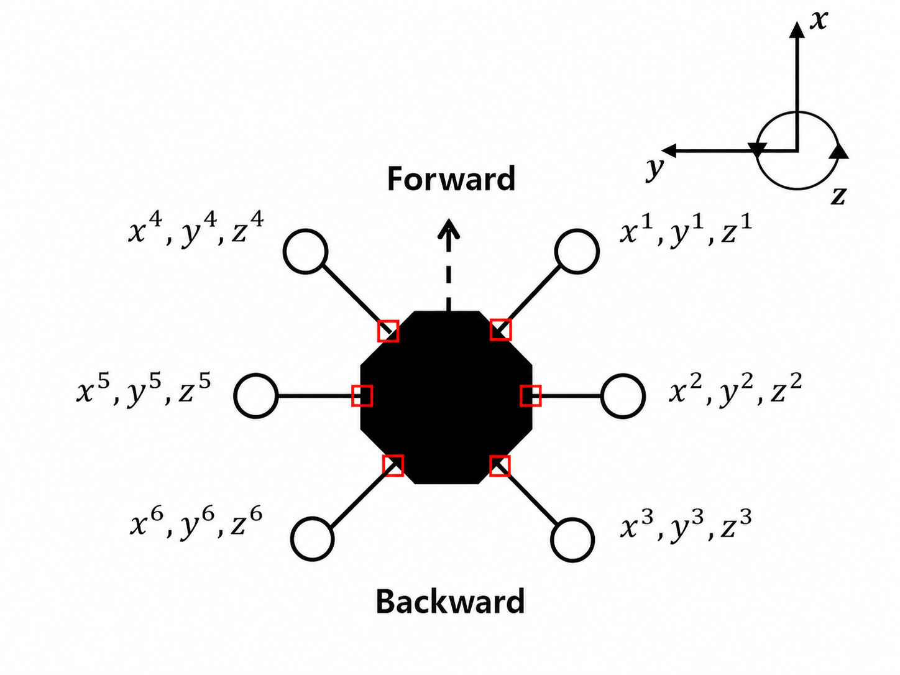
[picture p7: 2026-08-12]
SW/Controller/좌표축/다리 번호.png

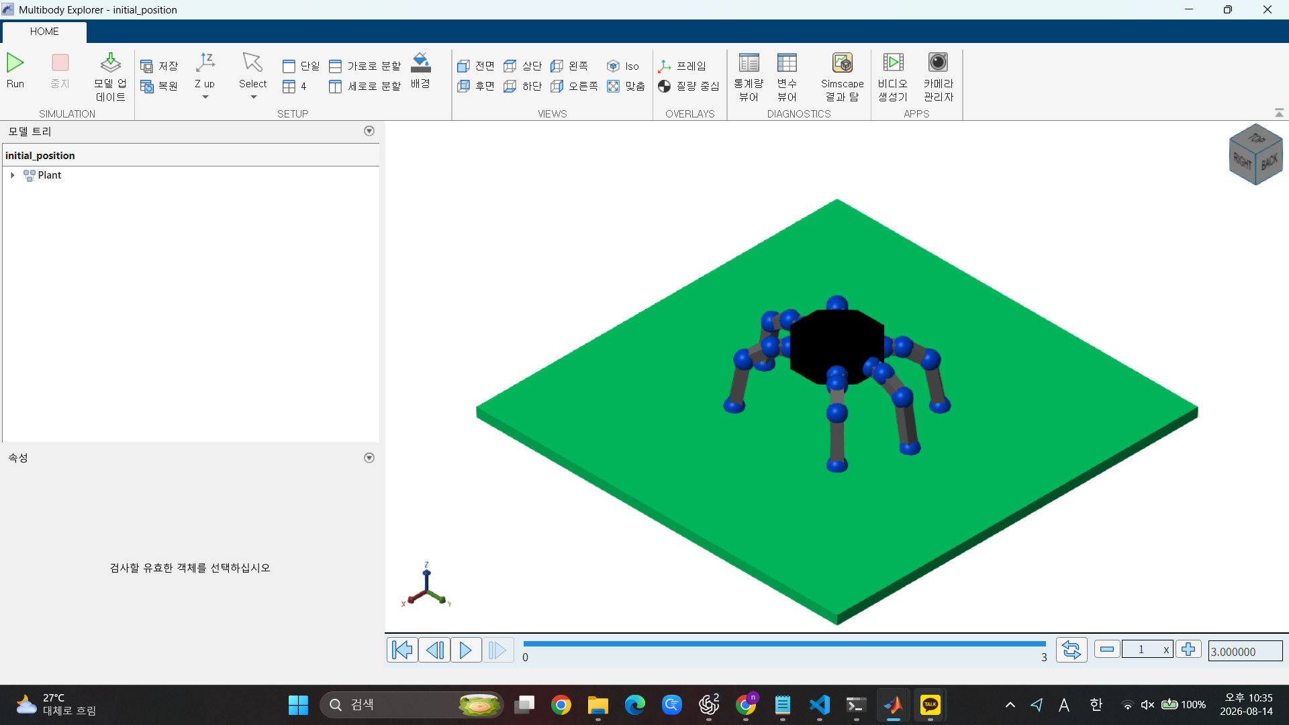
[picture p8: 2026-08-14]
SW/Controller/좌표축/초기 자세 전체 형상.png

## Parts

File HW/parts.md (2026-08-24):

# 하드웨어 부품 목록

Hexapod Robot 제작에 사용하는 주요 부품의 수량, 용도와 구매처를 정리한다. 실제 로봇에는 DS51150-270 서보 18개를 사용하며 나머지 수량은 예비 부품을 포함한다.

---

## 1. Main Controller / Computing Unit

### Jetson Orin Nano Super

- **개수**: 1개
- **용도**: 각종 센서를 종합해 이동 경로와 보행 방법 계산
- **구매링크**: [DeviceMart](https://www.devicemart.co.kr/goods/view?no=14990359)

### STM32 NUCLEO-F446RE

- **개수**: 1개
- **용도**: GPS, IMU, LoRa 통신 담당
- **구매링크**: [DeviceMart](https://www.devicemart.co.kr/goods/view?no=1376886)

### SSD

- **개수**: 1개
- **용도**: Jetson Orin Nano Super에 장착해 OS와 모델 구동
- **구매링크**: [DeviceMart](https://www.devicemart.co.kr/goods/view?no=12147824)

---

## 2. Actuator / Joint Parts

### DS51150-270 Servo Motor

- **개수**: 20개
- **용도**: 로봇 다리 관절 구동용 서보모터
- **구매링크**: [AliExpress](https://ko.aliexpress.com/)

### DS51150-270 Servo Horn 5pcs

- **개수**: 4개
- **용도**: 서보모터와 로봇 관절 연결
- **구매링크**: [AliExpress](https://ko.aliexpress.com/i/1005007393245886.html)

### 6703ZZ Deep Groove Ball Bearing

- **개수**: 20개
- **용도**: 다리 관절 회전 보조
- **구매링크**: [Coupang](https://www.coupang.com/vp/products/6143283810?itemId=11802532451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)

---

## 3. Mechanical Parts

### PLA Filament

- **개수**: 4개
- **용도**: 로봇 프레임 및 구조물 3D 프린팅
- **구매링크**: [Coupang](https://www.coupang.com/vp/products/6326227472?itemId=13209923756&vendorItemId=92097957520&q=pla+필라멘트&itemsCount=36&searchId=2c9f4d179589258&rank=3&searchRank=3)

### 스텐 육각렌치볼트 M4×10

- **개수**: 1봉
- **용도**: 로봇 조립용 볼트
- **구매링크**: [Coupang](https://www.coupang.com/vp/products/7877154060?utm_source=chatgpt.com)

---

## 4. Power System

### DXF Li-ion Battery 3S 7200mAh 100C

- **개수**: 2개
- **용도**: 서보모터 전원 공급
- **구매링크**: [RC9](https://rc9.co.kr/product/특가행사dxf-배터리-리튬-111v-7200mah-100c3s-dxf-한국총판-rc9-정품dxf01/80067/display/1/)

### DXF Li-ion Battery 2S 7200mAh 100C

- **개수**: 1개
- **용도**: 보드 및 센서 전원 공급
- **구매링크**: [AliExpress](https://ko.aliexpress.com/item/1005008268788282.html?gatewayAdapt=glo2kor)

### 고출력 스텝다운 5A 가변 DC 컨버터

- **개수**: 2개
- **용도**: 배터리 전압 강하용 DC-DC 컨버터
- **구매링크**: [DeviceMart](https://www.devicemart.co.kr/goods/view?no=1321141)

### 니토 미니 배터리 잔량표시 볼트메타

- **개수**: 3개
- **용도**: 배터리 잔량 및 전압 확인
- **구매링크**: [Coupang](https://www.coupang.com/vp/products/334419473?itemId=1067530756&vendorItemId=75456141668&q=리튬배터리+3S+잔량표시&itemsCount=36&searchId=6dd464417351806&rank=2&searchRank=2)

### 아두이노 3채널 5V 릴레이 모듈

- **개수**: 2개
- **용도**: 각 다리 서보모터 전원 공급 및 차단
- **구매링크**: [DeviceMart](https://www.devicemart.co.kr/goods/view?no=12147824)

### CANAL MR2-110-C5-BB Switch

- **개수**: 1개
- **용도**: 로봇 메인 전원 스위치
- **구매링크**: [DeviceMart](https://www.devicemart.co.kr/goods/view?no=38183)

---

## 5. Connector / Wiring

### AMASS XT60E-F Female Connector

- **개수**: 3개
- **용도**: 배터리 고정 및 충전용 커넥터
- **구매링크**: [RCBank](https://www.rcbank.co.kr/m2/goods/view.php?goodsno=95419)

### JST-XH Balance Charge Wire

- **개수**: 3개
- **용도**: 배터리 밸런스잭 연장선
- **구매링크**: [HobbyZone](https://hobbyzone.kr/product/jst-xh-2s3s4s6s-20cm-22awg-balance-charge-wire-배터리-밸런스잭-연장선/5304/)
- **비고**: 2S용 1개, 3S용 2개

### XT60-F 암/수 커넥터

- **개수**: 3개
- **용도**: 배터리-전선 연결 소켓
- **구매링크**: [DeviceMart](https://www.devicemart.co.kr/goods/view?no=1078005)

### 10AWG 실리콘 케이블

- **개수**: 10개
- **용도**: 메인 전원용 굵은 전선
- **구매링크**: [Coupang](https://www.coupang.com/vp/products/8537462031?itemId=24715590149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)

### 18AWG 실리콘 케이블

- **개수**: 10개
- **용도**: 모터 전원용 전선
- **구매링크**: [Coupang](https://www.coupang.com/vp/products/8264903762?itemId=23813552001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)

### 22AWG × 4C 전선

- **개수**: 20개
- **용도**: 센서 및 신호용 얇은 전선
- **구매링크**: [Coupang](https://www.coupang.com/vp/products/7156740267?itemId=18003337265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)

### LiDAR Cable

- **개수**: 1개
- **용도**: Livox Mid-360 LiDAR와 Jetson Orin Nano Super 간 통신
- **구매링크**: [DeviceMart](https://www.devicemart.co.kr/goods/view?no=12147824)

---

## 6. Sensor / Perception

### Livox Mid-360 LiDAR

- **개수**: 1개
- **용도**: 주변 지형 및 장애물 인식
- **구매링크**: [Coupang](https://www.coupang.com/vp/products/9250130341?itemId=27358998182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)

### Intel RealSense D435

- **개수**: 1개
- **용도**: 주변 지형 및 깊이 정보 인식
- **구매링크**: [DeviceMart](https://www.devicemart.co.kr/goods/view?no=13017227)

### WT931 9DOF IMU

- **개수**: 1개
- **용도**: 로봇의 기울기와 방향 측정
- **구매링크**: [DeviceMart](https://www.devicemart.co.kr/goods/view?no=10886274)

### Interlink FSR 402 Pressure Sensor

- **개수**: 6개
- **용도**: 로봇 발의 지면 접촉 여부 확인
- **구매링크**: [DeviceMart](https://www.devicemart.co.kr/goods/view?no=33870)

### MCP3008 ADC Module

- **개수**: 3개
- **용도**: STM32의 부족한 ADC 채널 보완
- **구매링크**: [DeviceMart](https://www.devicemart.co.kr/goods/view?no=12147824)

### NEO-M8N GPS Module

- **개수**: 1개
- **용도**: 로봇의 실시간 위치 좌표 확인
- **구매링크**: [DeviceMart](https://www.devicemart.co.kr/goods/view?no=15106909)

---

## 7. Communication / Remote Control

### RadioMaster Pocket ELRS 조종기

- **개수**: 1개
- **용도**: 로봇 수동 조종용 컨트롤러
- **구매링크**: [SUSUNG RC](https://susungrc.com/product/%EB%9D%BC%EB%94%94%EC%98%A4%EB%A7%88%EC%8A%A4%ED%84%B0-pocket-%EC%A1%B0%EC%A2%85%EA%B8%B0-elrs/2385/)

### ELRS-2.4G-NANO ESP8285 Receiver Module

- **개수**: 1개
- **모델**: DarwinFPV 2.4G ELRS Nano
- **용도**: RadioMaster Pocket의 ELRS 신호를 수신하여 CRSF UART로 STM32에 전달
- **구매링크**: [DeviceMart](https://www.devicemart.co.kr/goods/view?no=15138136)

### RYLR998 UART LoRa Module

- **개수**: 2개
- **용도**: 로봇과 컴퓨터 간 장거리 무선 통신
- **구매링크**: [Coupang](https://www.coupang.com/vp/products/7232535124?itemId=18355967552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)

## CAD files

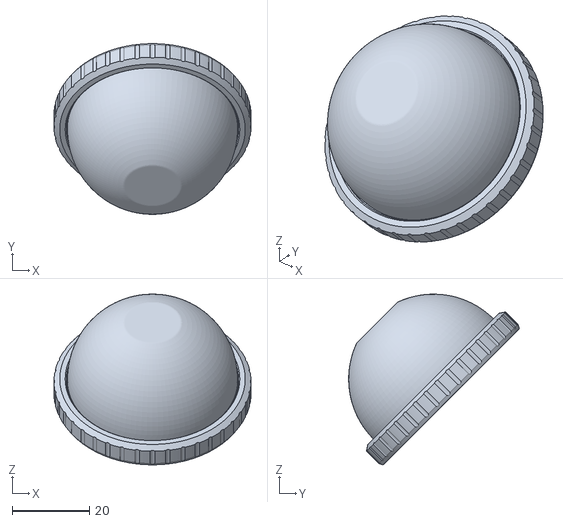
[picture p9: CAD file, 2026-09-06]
HW/urdf/meshes/mid-360-fov-asm_ver.ksh_MID-360_4_1_1_1.stl
51.0 x 44.2 x 44.2

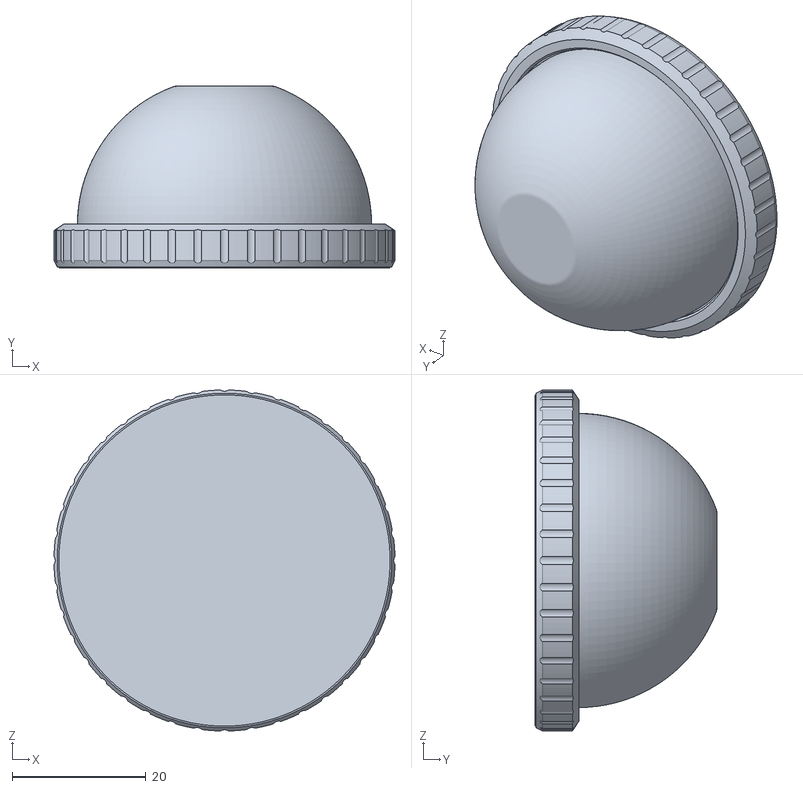
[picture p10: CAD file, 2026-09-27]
HW/urdf/versions/HEXAPEDAL_URDF_v2_description/meshes/mid-360-fov-asm_ver_ksh_MID-360_4_1_1.stl
51.0 x 27.2 x 51.0

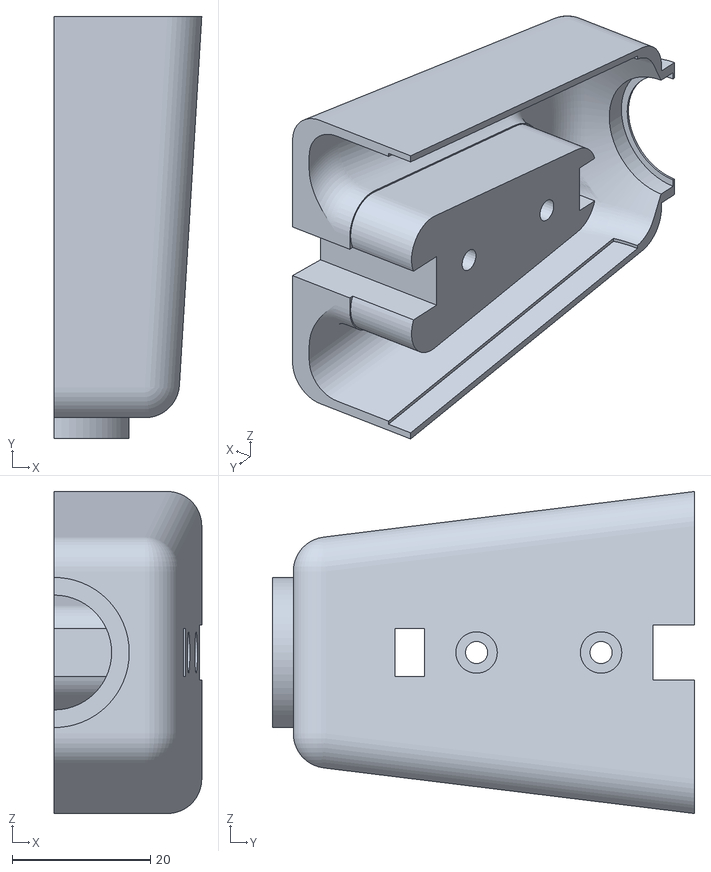
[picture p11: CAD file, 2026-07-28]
HW/stl_file/foot_2_output.stl
21.3 x 61.0 x 46.6

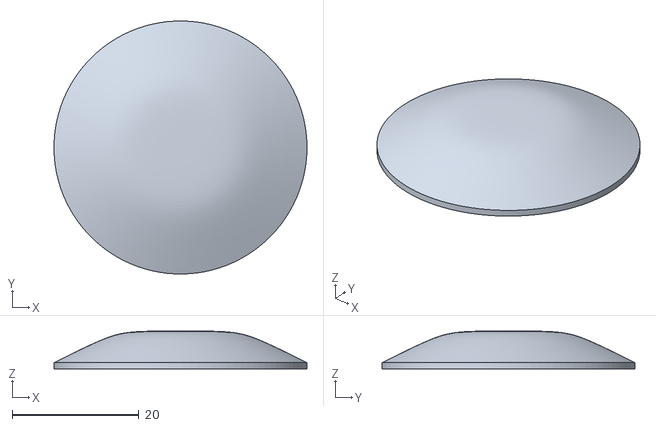
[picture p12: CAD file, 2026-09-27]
HW/urdf/versions/HEXAPEDAL_URDF_v2_description/meshes/RB_foot_4.stl
40.0 x 40.0 x 6.00

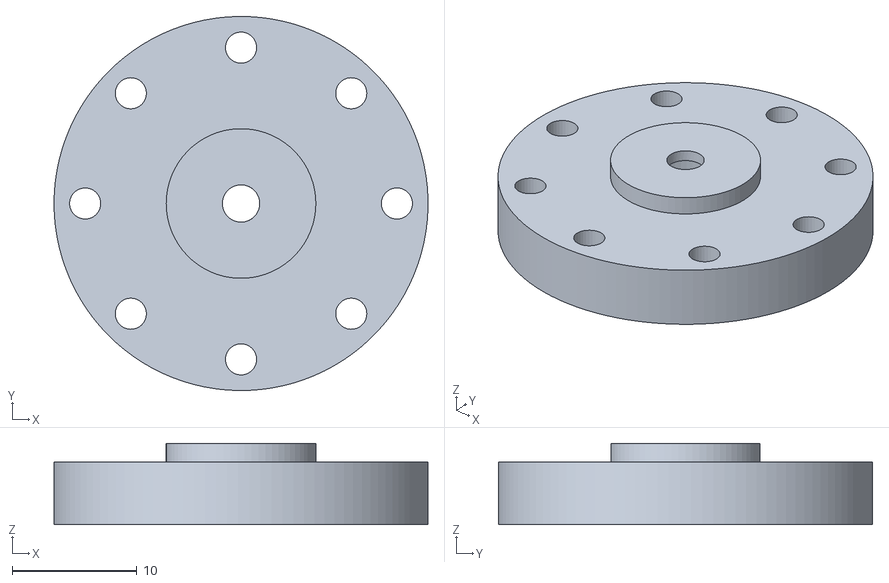
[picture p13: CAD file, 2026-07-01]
HW/urdf_earlyVersion/meshes/LB_motor_horn_3.stl
30.0 x 30.0 x 6.50

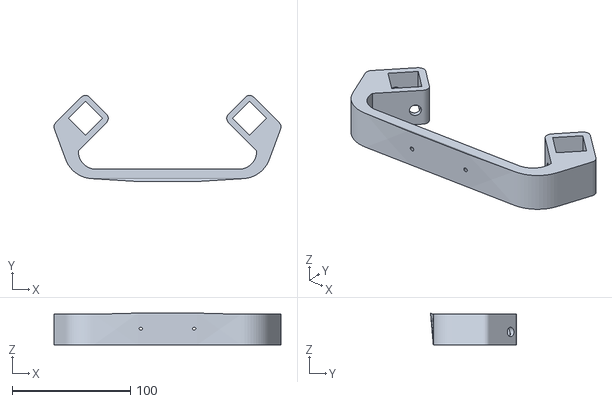
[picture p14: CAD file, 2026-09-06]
HW/urdf/meshes/제목_없음_1.stl
191.6 x 72.6 x 26.9

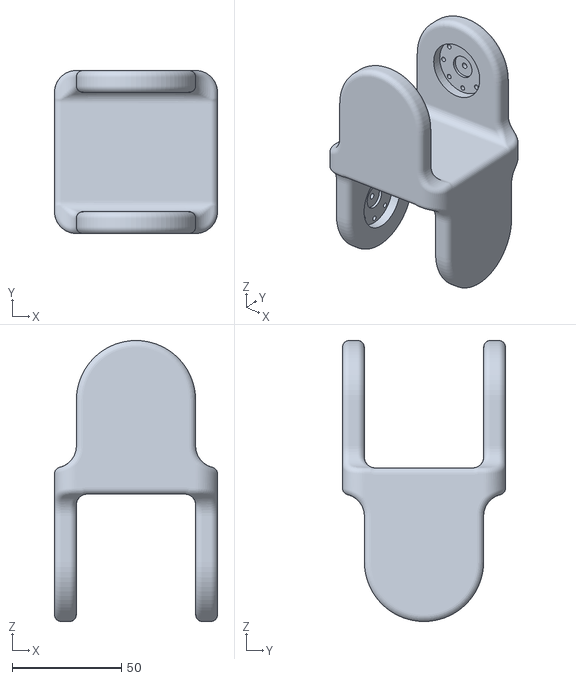
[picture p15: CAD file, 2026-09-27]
HW/urdf/versions/HEXAPEDAL_URDF_v2_description/meshes/RF_coxaR.stl
74.6 x 74.6 x 128.6

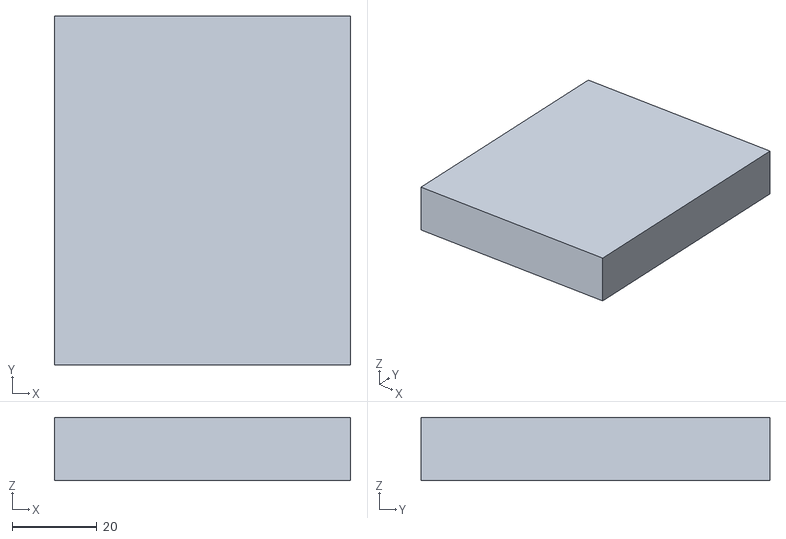
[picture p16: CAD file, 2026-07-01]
HW/urdf_earlyVersion/meshes/STM32_F446RE.stl
70.0 x 82.5 x 15.0

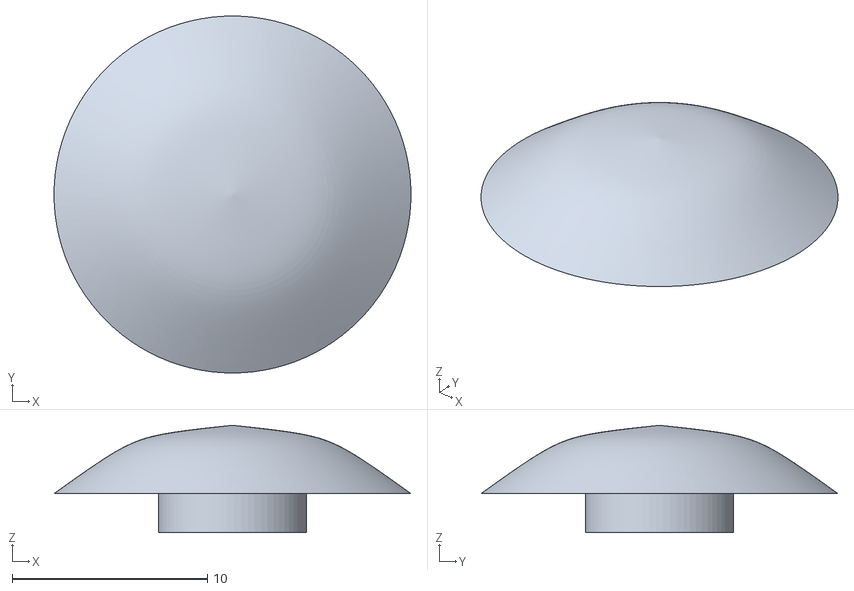
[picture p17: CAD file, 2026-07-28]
HW/stl_file/foot_3_output.stl
18.3 x 18.3 x 5.50

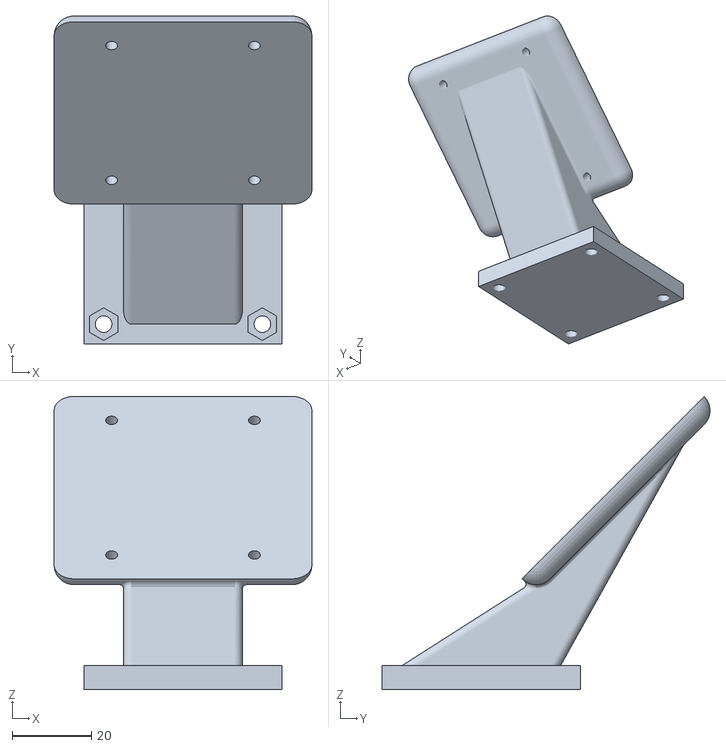
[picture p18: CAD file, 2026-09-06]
HW/urdf/meshes/M_column_3_final_1.stl
65.0 x 82.7 x 73.8

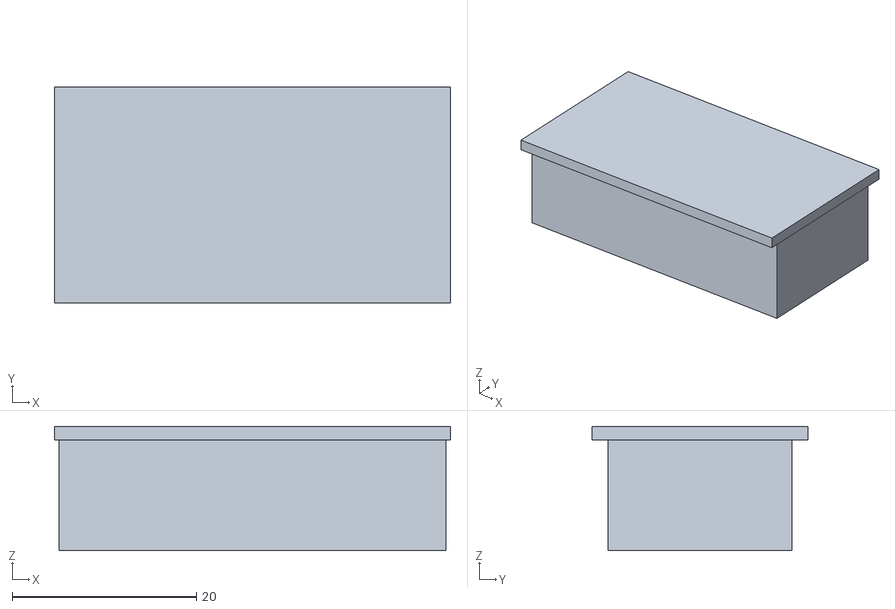
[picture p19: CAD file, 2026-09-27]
HW/urdf/versions/HEXAPEDAL_URDF_v2_description/meshes/Volt_Meter_3.stl
43.0 x 23.5 x 13.5

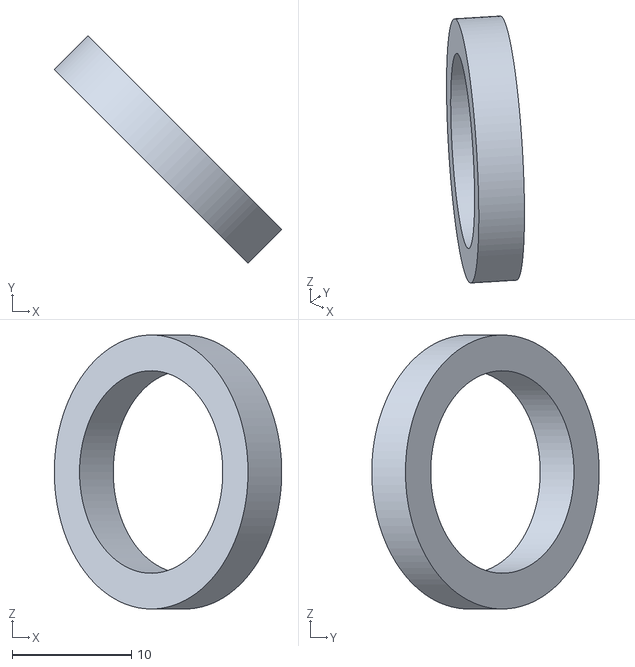
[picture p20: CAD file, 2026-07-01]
HW/urdf_earlyVersion/meshes/LF_bearing_2_1.stl
19.1 x 19.1 x 23.0

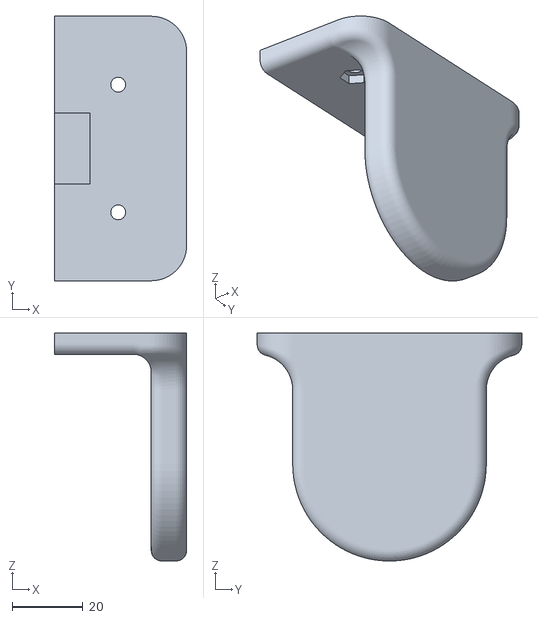
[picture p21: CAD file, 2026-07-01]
HW/stl_file/coxa4.stl
37.3 x 74.6 x 64.3

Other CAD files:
HW/gcode_file/flame2.gcode.3mf
HW/gcode_file/flame4.gcode.3mf
HW/stl_file/foot_1_output.stl
HW/gcode_file/coxa2.gcode.3mf
HW/gcode_file/flame3.gcode.3mf
HW/gcode_file/M_column_1.gcode.3mf
HW/gcode_file/M_column_2.gcode.3mf
HW/gcode_file/M_column_3.gcode.3mf
HW/gcode_file/M_hold.gcode.3mf
HW/gcode_file/coxa1.gcode.3mf
HW/gcode_file/coxa3.gcode.3mf
HW/gcode_file/coxa4.gcode.3mf
HW/stl_file/M_column_1.stl
HW/stl_file/M_column_2.stl
HW/stl_file/M_column_3.stl
HW/stl_file/M_hold.stl
HW/stl_file/coxa1.stl
HW/stl_file/coxa2.stl
HW/stl_file/coxa3.stl
HW/stl_file/flame1.stl
HW/stl_file/flame2.stl
HW/stl_file/flame3.stl
HW/stl_file/flame4.stl
HW/stl_file/link1_left.stl
HW/stl_file/link1_right.stl
HW/stl_file/link2_1.stl
HW/stl_file/link2_2.stl
HW/urdf/meshes/AMASS_XT60E_F_FeMale_2_1.stl
HW/urdf/meshes/AMASS_XT60E_F_FeMale_3_1.stl
HW/urdf/meshes/AMASS_XT60_F_FeMale_1_1.stl
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

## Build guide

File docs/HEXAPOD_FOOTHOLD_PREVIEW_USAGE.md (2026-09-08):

> 이 문서는 이전 개발 단계의 설계/사용 이력을 포함합니다. 현재 v4 contract, timing, 실행 경로는 [통합 문서](ADAPTIVE_INTEGRATION_V4.md)를 따릅니다.

# MuJoCo 보행·LiDAR 뷰어 사용법

최종 갱신: 2026-09-06. 기본 모드는 **펌웨어 제어기 연속 보행 + stage31 RL residual + MJX 동역학**이다.
사용자 요청에 따라 이번 수정의 GUI·추론·동역학 보행 검증은 실행하지 않았다.

## 시작과 환경

```bash
cd /home/huro/Hexapod-Robot
source /home/huro/.venvs/hexapod-mjx/bin/activate
bash scripts/view_foothold_planner.sh --terrain steps
```

기존 창을 닫고 다시 실행한다. 스크립트가 가상환경 Python을 직접 사용하므로 activate는 선택 사항이다.
MuJoCo/MJX, JAX, Brax, Orbax가 설치된 학습 환경을 사용하며 첫 실행에는 JAX 컴파일 시간이 필요하다.
GPU 정책/물리 계산은 별도 프로세스, LiDAR/map 계산은 CPU 스레드에서 처리한다.
컴파일 중 창은 조작할 수 있지만 보행 시작은 준비가 끝난 뒤다. 물리 시간은 HUD의 simulation을 본다.

| 구성 | 현재 구현 |
|---|---|
| 로봇 | 과거 학습의 box 몸체·capsule 링크·반지름 32 mm 구형 발 skeleton |
| 가중치 | `progress-v2-stage31-level6_20260828-111825_seed40`, checkpoint `000001703936` |
| 제어기 | 가중치에 대응하는 격리된 `0805164` v3 펌웨어 step |
| 주기 | policy 20 ms, firmware 5 ms, physics 2.5 ms |
| 몸체 상태/odom | MuJoCo 상태 사용; 실제 LiDAR+IMU odometry 구현은 후속 작업 |
| 정책 지형 입력 | LiDAR 높이 지도에서 15개 위치를 샘플링 |
| 물리/시각화 지형 | 같은 12×12 m 코스의 2 cm heightfield |
| GT 접근 | 환경의 물리·평가 및 별도 LiDAR 비교용; actor 지형 입력과 보정에는 사용하지 않음 |

현재 루트 `mjx/` 학습 코드는 v4/100 mm 계약이다. 뷰어의 stage31 v3/18-D 가중치에 이를 섞지 않는다.
당시 미커밋 코드 전체가 보관되지 않았으므로 기록 영상의 정확한 재현을 보장하지 않는다.

## 제어 구조와 이번 수정 이유

```text
속도·높이 명령 + 몸체/접촉 상태 → 펌웨어 nominal gait ─┐
                                                     ├→ Safety/IK → servo → MJX
LiDAR 높이 지도 + proprioception → stage31 residual ─┘

LiDAR 지도 → geometric 착지 후보 → 화면의 참고 마커
LiDAR 높이 샘플 ↔ 동일 XY의 simulator GT → 비교 지표/저장 전용
```

이전 구현은 관측된 경로를 월드 좌표 발 목표로 덮어쓰고, 착지 후 그 위치를 펌웨어 foot memory에
되돌려 넣었다. 이 경로와 펌웨어의 접촉·posture·지지 궤적이 충돌할 수 있었다. 사용자가 관측된
착지점 진입 때 IK 문제를 보고했으며, 실행 재현으로 직접 원인을 확정한 것은 아니다.

현재는 외부 경로/stance anchor 주입과 다리별 제어 모드 전환을 제거했다. 원래 펌웨어 step이
nominal 궤적, 스윙/지지/late landing, foot memory, posture, residual 해석, IK, 관절 속도 제한을 맡는다.
추가 어댑터는 policy action의 크기만 조절한다. 후보를 못 찾아도 기본 gait는 계속 진행한다.

- 정책이 읽는 15개 지형 샘플이 모두 미관측이면 action과 residual filter를 0으로 만든다.
- 관측이 생기면 목표 gain은 `--residual-scale × 유효 샘플 수/15`다. 0.5초 시정수로 증가/변화를 완화한다.
- 관측이 모두 만료되거나 scale이 0이면 residual을 즉시 0으로 지운다. 기본 제어기는 계속 동작한다.
- gain은 임시 관측 가용성 기준이며, 후보 patch 유효성이나 학습된 confidence를 뜻하지 않는다.
- v3의 원래 swing XY, swing Z 높이, stance Z, late-landing residual 규칙을 그대로 사용한다.
- GT 기반 pitch feedforward와 swing boost는 끈다. 지지 높이는 접촉 발 운동학으로 추정한다.

미관측 지형 입력의 0은 checkpoint 차원을 유지하기 위한 중립값이다. 지도에는 관측으로 기록하지 않는다.
기존 146-D actor는 유효 마스크/관측 나이를 입력받지 않아 공백과 실제 평지를 구분하지 못한다.
그 정보는 비교 파일에 저장하고, 향후 sensor student 학습 때 입력에 추가해야 한다.

**착지 후보 마커가 실제 발 목표는 아니다.** 후보 실패의 빨간 X도 기본 모드의 정지 명령이 아니다.
실제 명령은 흰 점이며, 알려진 장애물에 대한 별도 경로 보장 기능을 이 모드에 구현한 것은 아니다.
기존 환경의 IK·workspace 제한과 물리 실패 종료 조건은 남아 있다.

## 조작법

방향키는 목표 속도를 증감한다. 키를 놓아도 계속 움직이므로 창에 포커스를 두고 사용한다.

| 키 | 기본 `--controller trained` 모드 |
|---|---|
| ↑ / ↓, W / S | 전후진 command ±0.04 m/s; 범위 ±0.12 m/s |
| ← / →, Q / E | yaw command ±0.15 rad/s; 범위 ±0.3 rad/s |
| Space | 이동 command 0; 물리와 자세 제어는 계속 진행 |
| Enter | 물리 일시정지 / 재개 |
| PageUp / PageDown | 초기 높이 기준 trim ±2 cm; 범위 -5~+10 cm |
| H | 정책·물리·지도 초기화 |
| R | 인식 재시도; 물리 종료 상태이면 reset |
| 1~6 | RF/RM/RB/LF/LM/LB 후보 상세 보기 |
| M / L / G | 높이 셀 / 반환점 / MID-360 FOV 표시 |
| K | scan 켜기/끄기; 기존 관측은 60초 뒤 만료 |
| C | 지도 초기화 + 이동 command 0 |
| P | 계획·지도·제어 진단·LiDAR/GT 샘플 쌍 저장 |
| F / T / V | 추적 카메라 / 위에서 보기 / 전체 코스 |

A/D 횡이동은 checkpoint command에 없어 지원하지 않는다. 원본 run은 전진 0.06~0.12 m/s,
yaw=0으로 학습했으므로 후진·회전과 sensor 입력에서의 성능은 사용자가 별도로 확인한다.

## 사용자 확인 순서

먼저 같은 동역학 환경에서 residual 없이 비교한다.

```bash
bash scripts/view_foothold_planner.sh --terrain steps --residual-scale 0
```

1. ↑를 2번 눌러 전진한다. 관측 유무와 무관하게 `NOMINAL / RL=0`, gain 0으로 스윙이 이어지는지 본다.
2. 다시 기본 명령 또는 `--residual-scale 0.25`로 실행한다. 관측 샘플이 생기면 `NOMINAL + RL RESIDUAL`과 gain이 표시되는지 본다. `FOOTHOLD + RL`로 바뀌는 이전 구조는 제거했다.
3. K로 scan을 끄고 C로 지도를 지운 뒤 다시 전진한다. residual 0으로 기본 보행이 이어지는지 확인한다.
4. `IK valid`, `residual IK valid`, `reach limited`, 흰 목표와 실제 발을 비교한다. 첫 항목은 최종 IK, 두 번째는 residual 적용 전후 후보의 IK 수락 여부다.
5. 문제가 생긴 시점에 Enter로 멈추고 P로 저장한다. scale 0에서도 문제가 있으면 기본 제어기/물리 쪽, residual 적용 때만 생기면 정책·관측·보정 크기 쪽을 구분해 볼 수 있다.
6. `LiDAR policy samples n/15`와 `GT raster RMSE`를 확인한다. 관측 샘플이 없으면 RMSE는 `n/a`이며 오차 0으로 취급하지 않는다.

## 코스·지도·센서

초기 전방은 world +X다. 정면 4 cm 계단 6단, 좌측 4/8/12 cm 플랫폼과 징검다리,
우측 8° 경사와 돌출물, 뒤쪽 요철·둥근 바위가 있다. 독립 재생기의 6.5 cm 계단 7단과 다른 코스다.
2 cm heightfield는 원래 상자 모서리와 좁은 돌출물을 근사한다.

기본 measured TF는 밑면 중심에서 높이 **215 mm**, 전방 **13.529 mm**, 전방 기울기 **45°**다.
38° 변경은 사용자 요청으로 롤백했다.
base 기준 XYZ `(0, -0.013529, 0.1642) m`, RPY `(0, 45°, -90°)`다.
MID-360 FOV는 수평 360°, 수직 -7°~+52°, 거리 0.1~8 m, 기본 720×64 angular rays다.
실제 Livox 비반복 스캔 패턴의 재현은 아니다. URDF CAD 장착 chain과 measured override는 별도다.

별도의 새 23-D 파라미터 제어/학습 모드는 같은 스크립트에 `--controller adaptive`를 붙인다.
그 모드는 학습용 MJX 계단과 JAX 센서 지도를 사용하므로 이 문서의 stage31 코스·키·지도 설정과 구분한다.
실행/학습/확인 항목은 [adaptive 사용 가이드](HEXAPOD_MJX_ADAPTIVE_GAIT_USAGE.md)를 따른다.

지도는 odom 정렬 8×8 m rolling grid, 4 cm 셀, 60초 유지다. 몸체에 가린 지면은 채우지 않는다.
지도 불투명도 16%, 점군 22%, 후보 마커는 불투명하다. M/L/G는 표시만, K/C는 정책의 센서 입력에도 영향을 준다.
주황은 미관측 nominal 후보, 파랑/청록은 관측 기반 후보, 빨간 X는 후보 실패, 흰 점은 실제 제어 목표다.

## 저장 파일과 비교 모드

출력 경로는 `mjx/generated/foothold_preview/`다.

| 파일 | 내용 |
|---|---|
| `scene_manifest.json` | checkpoint·격리된 소스·센서 TF·residual 설정·GT 용도 |
| `latest_plan.json` | qpos, 후보, 실제 발 목표, scaled action/gain, IK 진단, LiDAR/GT 비교 지표 |
| `latest_map.npz` | 지도 높이·관측 여부·시각·odom 중심·점군 |
| `latest_lidar_gt_pair.npz` | 동일 15개 XY의 LiDAR/GT 높이, valid/age, support height, 입력 pose와 시각 |
| `policy/` | 격리된 v3 소스·MJB 모델·JAX cache |

GT 비교는 action 계산 후 수행하며 결과를 actor에 넣지 않는다. GT는 2 cm 코스 raster의 bilinear
기준이므로 MuJoCo 삼각형 표면과 모서리에서 차이가 날 수 있다. 오차는 관측된 유효 샘플만 계산한다.
P는 최근 한 쌍을 덮어쓴다. 이것은 비교 자료이며 대규모 데이터셋 수집기나 재학습 완료 모델이 아니다.
센서 정책의 후속 학습 구조는 [설계 문서](HEXAPOD_LIDAR_FOOTHOLD_RESIDUAL_PLAN.md)를 따른다.

```bash
# 예전 착지점 경로를 따라가는 기구학 모드: 물리/학습 residual 비교와 구분
bash scripts/view_foothold_planner.sh --terrain steps --controller nominal

# 기구학 모드에서 CAD mesh 확인
bash scripts/view_foothold_planner.sh --terrain steps --controller nominal --robot-model mesh

# 별도 v3 정책 재생기: 기록된 지형/GT 입력 사용
bash scripts/view_trained_policy.sh
```

기구학 모드만 A/D, Enter 제자리 swing, `--gait-swing-duration`, `--require-observed`를 지원한다.
`--revision`은 기구학 모델의 URDF snapshot에만 적용하며 기본은 로컬 `origin/main`이다.

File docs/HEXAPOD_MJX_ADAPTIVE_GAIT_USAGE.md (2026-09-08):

> 통합 브랜치의 실행/SPI 계약과 검증 범위는 [v4 통합 문서](ADAPTIVE_INTEGRATION_V4.md)가 기준입니다.

# MJX hybrid residual 보행 사용 가이드

업데이트: 2026-09-06. 브랜치 `codex/cartesian-residual-rl`.
구현과 정적 확인까지 진행했다. GUI 보행, JIT rollout, PPO, 아래 테스트의 실행 검증은 사용자에게 맡겼다.
새 24-D 학습 가중치는 없다. 계단 등판이나 안전한 gait 전환이 검증됐다는 뜻은 아니다.

## 경로와 실행

키 입력을 배제하고 보행 경로부터 확인하려면 시작 속도를 직접 준다.

```bash
bash scripts/view_foothold_planner.sh --controller adaptive \
  --terrain steps --perception lidar --stage0 --speed 0.04
```

방향키 또는 `W/S`는 전후 속도를 0.02 m/s씩 바꾸고 `A/D`는 yaw를 바꾼다.
입력이 들어오면 콘솔의 `command: vx=...`가 즉시 변한다. `v`는 변하는데 움직이지 않으면
같은 줄의 `mode`, `bootstrap`, `fault`와 다리별 `reason`을 확인한다. LiDAR blind-zone에서는
feasible foothold를 처음 얻을 때까지 stride 0.5 classical Tripod가 동작하고 이후 planner로 넘긴다.
이를 끄고 UNKNOWN→HOLD만 확인하려면 `--no-bootstrap-classical`을 추가한다.

```bash
cd /home/huro/Hexapod-Robot
source /home/huro/.venvs/hexapod-mjx/bin/activate

# Stage 0: RL 없이 GT 100% known으로 planner/controller 분리 확인
bash scripts/view_foothold_planner.sh --controller adaptive --terrain flat --perception oracle
bash scripts/view_foothold_planner.sh --controller adaptive --terrain steps --perception oracle

# 동일 코드에서 LiDAR 입력으로 실행. 같은 자세의 GT 비교 지표도 출력
bash scripts/view_foothold_planner.sh --controller adaptive --terrain steps --perception lidar --stage0
```

`--controller adaptive`가 새 구조를 선택한다. 생략하면 기존 stage31 비교 viewer다.
스크립트가 가상환경 Python을 직접 선택하며 `HEXAPOD_PYTHON`으로 바꿀 수 있다.
MuJoCo, MJX, JAX, mujoco-playground, Brax/Orbax가 있는 기존 `hexapod-mjx` 환경을 사용한다.
새 의존성을 설치하지 않았다. 첫 화면까지 JAX 컴파일 시간이 필요하며 새 검색의 성능은 아직 측정하지 않았다.

| 키 | 동작 |
|---|---|
| ↑ / ↓ | 전진 속도 증가 / 감소; 입력 후 계속 보행 |
| ← / → | yaw 명령 증가 / 감소 |
| Space | 속도·yaw를 0으로; 진행 중 swing은 접촉까지 처리 |
| Enter / H | 일시정지 / 환경 초기화 |
| C / M | 지도 초기화 / 지도 표시 |
| G / B | LiDAR FOV / 거절 후보 표시 |
| P | 최근 trace, map, 후보 진단, 모델, contract 저장 |

저장 위치: `mjx/generated/adaptive_gait/`. `foothold_diagnostics.json`에는 후보별 gate,
선택 index, 실제 latch index, 궤적 parameter가 들어간다. trace는 최근 500 policy tick이다.
`--gait-mode tripod`, `--gait-mode wave`, `--gait-mode hybrid`로 고정/혼합 비교한다. 기본은 hybrid다.

## 환경 구성과 데이터 흐름

학습에 쓰던 링크 collision skeleton을 사용한다. distal link 230 mm, foot sphere 반경 32 mm이며
IK endpoint와 collision/site는 구의 중심으로 맞췄다. 메시 기반 CAD 표시와 구분한다.
LiDAR는 기존 측정 TF를 유지한다: 기준 높이 215 mm, 전방 offset 13.529 mm, 위를 보는 45° mount.
FOV는 MID-360 H360°, V[-7°, +52°], range 0.1–8 m. G로 표시하는 선은 시야각 경계다.
policy 20 ms, firmware tick 5 ms, LiDAR 100 ms, 90×8 ray, dropout 5%, noise 5 mm,
지도 cell 5 cm다. 시뮬레이터 pose/velocity/contact를 이상적인 state estimator로 사용하며 실제 LIO는 연결하지 않았다.

```text
LiDAR ray → rolling height map → support plane / edge / confidence
command → nominal foothold → 25-candidate search → safe reference
safe reference + RL XY → 같은 safe set으로 projection → terrain Z
path maximum height + margin + RL clearance → sampled path / IK gate
Tripod normal → short-step Tripod → known-infeasible이면 Wave → HOLD
phase boundary + all contacts → 목표/높이/궤적 parameter latch → 단일 controller / IK
```

`lidar`: actor와 planner에는 LiDAR만 사용한다. GT는 critic, reward/종료 판정, 비교 metric에만 사용한다.
`oracle`: GT height와 100% known/age 0으로 같은 planner를 실행한다. debug 전용이며 checkpoint/PPO에 쓰지 않는다.
`teacher`: GT 높이를 쓰되 LiDAR known mask는 유지한다. oracle과 다르다.
`blind`: 관측 안전 gate를 우회하는 명시적 nominal controller 진단이다. 지형 적응·hybrid 안전 fallback이 아니다.

최신 설계에 맞춰 **UNKNOWN은 기본 hybrid에서 HOLD**한다. 첫걸음 주변이 관측되지 않으면
자동으로 미관측 지형을 밟지 않는다. 초기 사각지대가 지속되면 그대로 정지할 수 있다.
이전 요청의 무관측 첫걸음 자체만 비교하려면 아래 debug 명령을 쓴다.

```bash
bash scripts/view_foothold_planner.sh --controller adaptive --terrain flat --perception blind
```

## 후보·workspace·안전 조건

각 다리의 nominal 주변 controller XY `[-8,-4,0,4,8] cm`의 25개 후보를 검사한다.
search ±8 cm는 허용 residual ±4 cm와 별개다. IK 링크 길이는 74/121/230 mm,
기본 발은 leg root에서 수평 218.728 mm, Z -287.006 mm다. ±8 cm 전부가 도달 가능하다는 뜻은 아니다.
각 후보의 endpoint와 21개 궤적 sample에서 실제 link IK, reach 여유 1 mm, joint 여유 1°를 확인한다.

support는 중심 known 필수 + coverage≥0.6 + 비공선 plane fit이 가능해야 한다.
중심과 일직선 이웃 2개만 있는 3/5 관측은 거절한다. 관측된 cell만으로 plane을 맞추고,
RMS 8 mm, slope 25°, 이웃 단차/cell spread 25 mm, foot-radius+5 mm edge 여유를 검사한다.
주변 5×5 cell의 관측된 단차로 edge distance를 계산하며, 미관측 edge가 없다고 보증하지 않는다.
normal/slope, coverage/confidence/age, 관측 support 폭·길이, path max/known fraction,
IK/joint margin을 고정 shape로 계산한다. support 폭·길이는 world grid 축상의 연속 관측 길이다.

경로는 21개 sample과 구형 발의 5점 footprint로 관측 장애물을 검사한다.
path known fraction≥0.6이어야 SAFE다. full mesh/다리 링크/몸통 swept collision 검사는 아니다.
RL XY는 reference 주변 ±4 cm 이내의 안전 후보로 projection하므로 결과는 4 cm grid에 양자화된다.
요청 clearance/timing이 실패하면 neutral reference 궤적으로 복구하며, 그 reference도 없으면 HOLD다.

Tripod는 다리별 top-3, 조합 27개에 대해 현재 stance와 다음 landing support polygon의
CoM 여유 12 mm를 검사한다. Wave는 현재 한 발 후보와 5발 stance를 검사한다.
각 phase의 stance IK를 5개 미래 body pose에서도 검사한다. 정적 CoM 근사이며 동적 안정성 증명은 아니다.
`Lmax_scale`은 `[1.3,1,.75,.5,.25,.125]` 중 통과한 최대 scale이다. 연속 최댓값이 아니다.
이동 성분의 최대 phase 이동 거리는 `abs(v_command)*1.0*Lmax_scale` m이다.

## action / observation 계약

`adaptive_hybrid_geometry_residual_24_v4`. 다리 순서 RF RM RB LF LM LB.

| index | semantic |
|---|---|
| 0:12 | 6다리 safe reference 기준 XY residual, X ±6 cm / Y ±4 cm; 별도 local25 후보, Z action 없음 |
| 12:18 | path-required clearance 위의 여유 residual ±4 cm |
| 18 / 19 / 20 | body roll ±5° / pitch ±10° / height ±3 cm |
| 21 | 요청 stride scale 0.5–1.3; supervisor는 필요시 0.125까지 축소 |
| 22 | apex plateau 중심 phase residual ±0.15 |
| 23 | XY transfer 중심 phase residual ±0.15 |

Z는 terrain surface + foot radius로 IK에 전달한다. 높이 기준은
`required=max(path_max-max(start_surface_z,landing_surface_z),0)`;
`clearance=clip(max(required+0.06+RL, required+0.02, 0.04),0.04,0.18)`이다.
18 cm 제한으로 required+margin을 못 만족하면 거절한다.
body normal 기반 roll/pitch baseline(각 ±12°) 위에 residual을 더하고 기존 자세/IK gate가 제한한다.
action=0도 planner baseline을 사용한다. 비활성 leg action은 현재 swing에 적용하지 않는다.

기존 quintic lift/transfer/lower를 유지했다. apex는 단일 Bézier 점이 아니라
Z plateau 중심이며 최종 범위 0.3–0.7, plateau 폭 0.4다.
상승 시 앞당기고 하강 시 늦추는 geometry baseline을 사용한다.
transfer 중심은 0.35–0.65, 이동 구간 폭 0.5다. 해당 변화도 같은 path/IK 검사를 통과해야 한다.

phase duration action은 제거했다. Tripod `clip(1.0*scale,0.5,1.4)`초,
Wave `clip(1.0*scale,0.6,1.4)`초, speed scale 0.2, stance 5 phase다.
속도에도 `scale*baseline_period/period`를 적용한다. Adaptive 상한은 전후0.10 m/s, yaw18°/s로 main과 맞춘다.

actor **4434-D** = proprio 157 + global 23 + reference 54 + 6×25×28 candidate.
critic **4749-D** = actor + GT/error 300 + terrain 15.
proprio는 기존 155 필드를 유지하고 accepted/previous action 증가로 157이 됐다.
global에는 vy command(현재 0), roll/pitch, contact 기반 body clearance, slip 6,
current gait, active swing mask 6, supervisor decision, maximum stride, Tripod/Wave feasibility,
mean confidence, support margin이 들어간다. reference는 다리별 body XYZ·nominal까지 거리·valid 및 local residual dx/dy extrema4개다.
candidate 28개 필드의 순서/정규화는 `adaptive_foothold_estimator.CANDIDATE_FEATURES`와 feature 조립 코드가 기준이다.
normal/slope는 world 축, candidate offset은 controller 축이다.
새 shape/source SHA 계약은 이전 adaptive24-D v3, 23-D 및 stage31 18-D checkpoint 로드를 거절한다.
기존 18-D controller/checkpoint 경로는 유지한다.

## main Wave 포팅과 전환

참고 revision `origin/main`의 `9752c760`; 상세 파일은 [구현 전 분석](HEXAPOD_HYBRID_GAIT_ANALYSIS.md)에 있다.
순서는 **RF → LB → RM → LF → RB → LM**이다.
첫 6 Wave phase는 stance 속도 절반, phase 시작 전 all-contact 100 ms 대기,
airborne 확인 후 progress≥0.5의 Early Landing, raw contact 후보 동결,
Late Landing 0.12 m/s 아래·0.096 m/s 안쪽, 최대 10 cm 검색 후 fault HOLD를 포팅했다.
support contact를 잃으면 phase를 멈추고 빠진 support만 검색한다. Late 동안 stance 적분도 멈춘다.
fault는 명령 해제 후 재무장한다. 실제 접촉은 20 ms policy sample로 확인하므로 하드웨어 10 ms FSR와 시간 해상도가 다르다.

모드 전환은 swing 완료 후 다음 all-contact phase 경계에서만 적용한다.
Wave→Tripod는 다음 두 Tripod phase가 feasible인 상태를 0.5초 유지하고 Wave 체류 2초를 요구한다.
두 번째 preview는 첫 착지의 가상 contact/발 위치와 root 직선 이동을 사용하며 yaw 연속 예측은 근사다.
main의 Tripod 두 phase 명령 묶음 대신 안전 supervisor는 매 phase에서 재검토한다.
현재 swing의 world landing Z/XY와 clearance/timing은 latch된다. 새 map이 목표를 이동시키지 않는다.
새 장애물에 대한 mid-swing 재계획/abort는 아직 없고 contact recovery와 매 tick IK 제한을 사용한다.

## 화면에서 확인할 것

| 상황 | 기대 / 확인 |
|---|---|
| flat oracle | action 0, normal Tripod, 후보/목표 안정, 연속 swing |
| steps 접근 | edge/거리 → short stride; terrain Z / apex / pitch 변화 |
| Tripod 불가·Wave 가능 | known-bad + short 실패 로그 → all-contact 경계에서 한 발씩 |
| 평지 복귀 | 두 phase feasibility와 hysteresis → Tripod |
| 후보 없음 / map 지우기 | UNKNOWN 또는 unsafe 사유와 HOLD; 진행 중 swing은 기존 latch 유지 |
| oracle도 실패 | workspace / IK / path / support / scheduler 로그 확인 |
| oracle만 성공 | LiDAR density, TF, age, coverage, edge filter 확인 |

회색 UNKNOWN, 노랑 LOW_COVERAGE, 주황 EDGE/ROUGH, 파랑 IK, 보라 PATH, 초록 SAFE,
흰색 reference, 빨강 selected/latched. 청록 map은 alpha 0.14다.
콘솔은 다리별 candidate_total/known/coverage_pass/surface_safe/ik_safe/path_safe,
ref/selected/active index와 residual rejection을 출력한다.
초록이 있어도 support 조합·stance IK·contact·hysteresis가 실패하면 phase는 시작하지 않을 수 있다.

`--stage0`는 동일 pose·명령의 oracle 대비 safe recall, false-safe rate,
unknown fraction, reference XYZ error, edge precision/recall을 추가 계산한다.
reference error는 양쪽 reference가 있는 다리만 비교한다(`oracle_compared`).
map MAE도 관측 cell만 비교한다(`map_compared_count`). 분모 0 지표를 성능 성공으로 해석하지 않는다.
LiDAR 스캔 미실행인 oracle 화면의 map MAE는 n/a다. 이 지표들은 현재 sample 기반 oracle 기준이며 실제 접촉 성공률은 별도 확인해야 한다.

## 사용자 확인 후 학습

Stage 0에서 planner가 실패하면 PPO를 시작하지 않는다. 학습은 자동 실행하지 않았다.

```bash
# Stage 1: Tripod only / flat
bash scripts/train_adaptive_gait.sh --stage 1 --perception lidar --terrain-level 0 \
  --num-envs 64 --timesteps 10000000 --output mjx/runs/hybrid-s1-flat

# 같은 24-D checkpoint로 ramp → 5cm stairs 순차 이관 (각 실행은 별도 output)
bash scripts/train_adaptive_gait.sh --stage 1 --terrain-level 3 \
  --restore mjx/runs/hybrid-s1-flat --output mjx/runs/hybrid-s1-ramp
bash scripts/train_adaptive_gait.sh --stage 1 --terrain-level 5 \
  --restore mjx/runs/hybrid-s1-ramp --output mjx/runs/hybrid-s1-steps

# Stage 2: Wave only, 먼저 flat에서 contact/sequence 학습
bash scripts/train_adaptive_gait.sh --stage 2 --terrain-level 0 \
  --restore mjx/runs/hybrid-s1-steps --output mjx/runs/hybrid-s2-flat
# 이후 Stage 2도 level 3 → 5 순차 학습. 완료한 run으로 Stage 3 시작
bash scripts/train_adaptive_gait.sh --stage 3 --terrain-level 5 \
  --restore mjx/runs/hybrid-s2-steps --output mjx/runs/hybrid-s3-steps

bash scripts/view_foothold_planner.sh --controller adaptive --terrain steps \
  --checkpoint mjx/runs/hybrid-s3-steps
```

`--restore`는 같은 source 계약의 가중치/normalizer 초기화이고 optimizer 재시작이다.
terrain/gait stage는 변경 가능하다. teacher는 `--perception teacher`, LiDAR 이관은
`--init-teacher RUN`; 이는 weight transfer 후 PPO이며 별도 imitation trainer는 아니다.
level 0 flat, 3/4 ramp 8°/15°, 5부터 stairs, tread 25 cm. hfield rough level 1/2는 ray 지원 때문에 거절한다.
`--wandb`로 기존 계정의 새 run을 기록한다. 대규모 env 수/메모리/throughput은 측정 전이다.

reward는 기존 진행/속도/자세/높이, residual/action rate, 충돌/IK/관절 제한 항목에
landing error·slip·projection·residual rejection을 더한다. 속도 목표는 수락한 gait 속도에 맞춘다.
Wave cost 0.005/s, mode switch cost 0.01로 안전 penalty보다 작게 둔다.
불필요한 apex는 기존 swing-height cost, body tilt는 자세 목표 오차와 residual cost로 억제한다.
별도 learned gait selector는 구현하지 않았다.

추가한 단위 테스트는 사용자가 필요할 때 실행한다. 에이전트가 실행하지 않았다.

```bash
python -m unittest discover -s mjx/tests -p test_adaptive_hybrid.py
# legacy 회귀가 필요할 때
python -m unittest discover -s mjx/tests -p test_firmware_mjx_controller.py
```

현재 확인 범위는 문법/CLI/정적 계약뿐이다. 전체 형상 collision, 센서 사각지대 대응,
동적 support 안정성, JIT/batch 메모리, 실제 등판과 sim-to-sim은 사용자 검증 후 이어갈 항목이다.

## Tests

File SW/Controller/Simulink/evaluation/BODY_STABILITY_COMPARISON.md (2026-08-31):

# 가상 몸체 자세와 문헌 실측 참고값

2026-08-31 기준. 최신 사용자 요청에 따라 **기존 실행에서 만든 VirtualIMU 값을 가상 자세 결과로 채워 넣는다.** 실제 몸체 자세 측정값이나 보행 안정성 검증 결과로 표시하지 않는다. 원본 신호에 임의 노이즈나 목표 수치를 추가하지 않는다.

## 비교 기준

| 로봇·보행 조건 | Roll RMSE (°) | Pitch RMSE (°) | 데이터 상태 |
|---|---:|---:|---|
| HexWalker II, Tripod | 0.390 | 0.366 | 문헌의 실제 로봇 시험 |
| HexWalker II, Quadrangular | 0.403 | 0.290 | 같은 로봇의 다른 보행 방식 |
| HexWalker II, Pentagonal | 0.265 | 0.284 | 같은 로봇의 다른 보행 방식 |
| 우리 Classical, **VirtualIMU** | **0.000** | **0.000** | 전진 명령 7 ≤ t < 10 s, 명령 기반 가상 신호 |
| 우리 로봇, 실제 몸체 자세 | 미평가 | 미평가 | 유효한 몸체 자세 로그 미확보 |

출처: F. Zhang et al., *Straight Gait Research of a Small Electric Hexapod Robot*, Applied Sciences 11(8), 3714 (2021), Section 6.3 및 Table 5. [논문 원문](https://www.mdpi.com/2076-3417/11/8/3714).

문헌의 세 행은 서로 다른 로봇이 아니다. 각 보행 방식의 시험 시간은 12, 24, 60초이며 실제 이동 거리는 각각 0.345, 0.335, 0.324 m이다. 이를 나누어 계산한 시험 평균 속도는 약 0.0288, 0.0140, 0.0054 m/s로 서로 다르다. 따라서 RMSE만으로 보행 방식이나 다른 로봇의 우열을 단정하지 않는다. 우리 Tripod 제어기의 우선 참고 대상은 첫 번째 행이다.

우리 가상 RMSE는 200 Hz의 600개 표본에서 산출했다. 이 구간에서 가상 Roll·Pitch 및 목표 자세가 모두 0°이므로 RMSE도 정확히 0이다. 실제 몸체의 보행 흔들림이 없다는 뜻이 아니며, HexWalker II보다 안정적이라는 근거로 사용하지 않는다.

## 가상 자세 요약표

| 평가항목 | 가상 결과 | 평가 구간 |
|---|---:|---|
| Roll RMSE | 0.000° | 전진 명령 7 ≤ t < 10 s |
| Pitch RMSE | 0.000° | 전진 명령 7 ≤ t < 10 s |
| Roll 최대 절댓값 | 18.079° | 전체 0–81 s, 의도적 자세 변경 포함 |
| Pitch 최대 절댓값 | 27.835° | 전체 0–81 s, 의도적 자세 변경 포함 |
| Roll 최대–최소 변화폭 | 33.677° | 전체 0–81 s, 의도적 자세 변경 포함 |
| Pitch 최대–최소 변화폭 | 34.965° | 전체 0–81 s, 의도적 자세 변경 포함 |

전진 구간의 최대 절댓값과 최대–최소 변화폭은 두 축 모두 0°이다. 전체 시험의 큰 자세 변화량을 전진 보행의 흔들림으로 표시하지 않는다. 위 값들은 저장된 원본 시뮬레이션 로그를 후처리한 가상 신호 통계이며, 실측값 또는 새 동역학 시뮬레이션 결과가 아니다.

## 산출 지표

평지에서 목표 Roll·Pitch를 0°로 유지하는 전진 보행을 기준 시험으로 정한다.

- 주 지표: Roll RMSE = sqrt(mean((roll - roll_ref).^2)), Pitch RMSE = sqrt(mean((pitch - pitch_ref).^2)). 단위는 °이다.
- 보조 지표: 각 축의 표준편차, 최대 절대 자세 오차, 최대–최소 변화폭을 함께 기록한다. 이 지표들은 서로 대체하지 않는다.
- 자세를 의도적으로 기울이는 시험은 수평 유지 보행 시험과 분리한다.
- 정지·기립·보행 구간을 구분하고 시작·종료 기준을 시험 전에 정한다. 이상 구간을 결과가 좋아지도록 임의 제거하지 않는다.
- 센서 장착 오차는 별도의 정지 교정 구간으로 보정하고, 보행 구간 평균을 빼서 자세 편향을 숨기지 않는다. 필터와 좌표계 정의를 명시한다.
- 속도, 지면, 보행 주기, duty factor, 몸체 높이, 하중, 표본 주기, 시험 시간 및 반복 횟수를 함께 기록한다. 비교 문헌과 맞지 않는 조건은 차이로 명시한다.

위 항목 중 시험 방법은 우리 평가를 위한 제안이다. 문헌에서 동일한 반복 시험이나 전처리를 수행했다는 의미가 아니다. Roll·Pitch RMSE는 자세 유지 성능을 나타내며 전복 여부나 지형 통과 성공률을 모두 대신하지는 않는다.

## 가상 결과의 해석 제한

1. `Plant/VirtualIMU`는 지연된 자세 명령을 Roll·Pitch 출력으로 반환한다. 중력·접촉력 때문에 발생하는 몸체 흔들림의 측정값이 아니다.
2. 기존 `plant.slx`는 몸체와 World Frame 사이가 강체 변환으로 연결돼 있어 자유로운 몸체 운동을 평가하지 않는다.
3. `TestContact`는 보행 위상과 시간으로 접촉 여부를 생성한다. 실제 발–지면 힘으로 판정한 접촉이 아니다.

따라서 기존 `metrics.json`의 `virtual_*` 및 `max_abs_virtual_*` 값, 가상 자세 그래프, 내부 전복 Fault 부재를 몸체 안정성 근거로 사용하지 않는다. 관절·발끝 추종 RMS도 몸체 자세 RMSE로 환산하지 않는다. 원본 로그는 재현과 제어기 디버깅 목적으로 보존한다.

## 유효한 우리 데이터 확보 방법

**실제 로봇 시험:** 몸체에 고정된 IMU의 시간·Roll·Pitch와 목표 자세, 보행 구간을 함께 저장한다. 센서의 단위와 축, 교정·필터 설정, 위 시험 조건을 기록한다. 현재 저장소에서 별도의 실측 IMU 로그는 확인하지 못했다.

**동역학 시뮬레이션:** 원본과 분리된 모델에 몸체의 6자유도 운동, 발–지면 접촉과 마찰, 적절한 질량·관성·구동 특성을 구성한다. 자세 명령 대신 World Frame에 대한 몸체의 계산된 회전을 기록하고, 접촉 피드백도 실제 계산된 접촉에서 얻는다. 초기 정지 지지, 접촉 반력, 몸체 이동, 시간 간격에 따른 결과 변화를 점검한 뒤 보행을 평가한다. 물리 파라미터와 검증 범위는 공개해야 한다.

후자의 값은 **동역학 시뮬레이션 결과**이며 실제 IMU 측정값으로 표시하지 않는다. 모델을 구성했다는 사실만으로 실물 성능이 검증되는 것은 아니다. 이번 확인에서는 동역학 보행 모델을 새로 구성하거나 실행하지 않았다.

## 그림 8 처리

새 그림은 [figure_08_body_attitude_comparison.png](figure_08_body_attitude_comparison.png)이다. 가상값과 실측값을 색상·레이블로 구분하고, 실제 보행 안정성 검증이 아니라는 제한을 그림 안에 표시한다. 편집 파일은 같은 이름의 `.fig`, 표는 `body_attitude_comparison.csv`, 계산 요약은 `virtual_imu_metrics.json`, 전진 구간 신호는 `virtual_imu_forward.csv`에 저장한다.

가상값이 정확히 0이면 그대로 표시한다. 이는 결측값을 0으로 대체한 것이 아니며, 실제 몸체 흔들림이 0이라는 의미도 아니다. 실제 몸체 성능은 별도의 미평가 행으로 유지한다. 기존 `figure_08_hexapod_comparison.png`는 속도·추종 지표에 관한 이전 참고 그림으로 보존한다.

이 폴더에서 MATLAB 함수 `make_body_stability_figure`를 실행하면 원본 `simulation_raw.mat`에서 그림과 표를 재생성한다. 기존 후처리와 같은 200 Hz 시간축으로 선형 보간하며, 평가 구간은 이전 발끝·관절 시험과 같은 7 ≤ t < 10 s이다. 목표 Roll·Pitch가 0°인지를 확인한 뒤 목표 대비 RMSE를 산출한다.

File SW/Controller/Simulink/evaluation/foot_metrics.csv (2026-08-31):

leg | rmse_mm | max_mm | excursion_cm
1 | 3.25595204322456 | 8.28326351712987 | 21.9184204501298
2 | 3.33084144010335 | 8.31882941328544 | 21.9583873941326
3 | 3.54243201269878 | 8.63052163661731 | 22.0334911251901
4 | 3.29778203708881 | 8.27067778454171 | 21.918871440172
5 | 3.30814360461468 | 8.32601099515821 | 21.9543082171607
6 | 3.56177362589909 | 8.62155908085113 | 22.007447308829

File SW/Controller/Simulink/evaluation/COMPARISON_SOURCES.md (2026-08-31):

# 사진 8 비교 수치와 출처

이 문서는 이전 속도·발끝·관절 참고 그림의 출처이다. 최신 요청으로 만든 가상 Roll·Pitch 그림의 출처와 수치는 [가상 몸체 자세와 문헌 실측 참고값](BODY_STABILITY_COMPARISON.md)을 참고한다.

작성일: 2026-08-31. 현재 Classical의 Simulink 실행 결과와 RHex, PhantomX AX, HAntR의 공개 문헌 수치를 참고 비교했다. 서로 같은 조건으로 실행한 벤치마크가 아니며 Residual-RL 결과는 포함하지 않는다.

| 로봇 | 실제 주행 최대 속도 (m/s) | 발끝 RMS 오차 (mm) | 관절 RMS 오차 (°) | 근거 |
|---|---:|---:|---:|---|
| 현재 Classical | 미평가 | 3.385 | 0.400 | 저장된 `metrics.json`, 몸체 고정 시뮬레이션 |
| RHex | 0.55 | 미확보 | 미확보 | [1], Table 1 |
| PhantomX AX | 0.29 | 미확보 | 미확보 | [2], Table 1 |
| HAntR | 0.43 | 미확보 | 미확보 | [2], Table 1 |

현재 Classical 오차는 2026-08-31에 실행한 `plant.slx`의 7 ≤ t < 10 s에서 계산했다. 발끝은 6개 다리의 3차원 목표–응답 거리, 관절은 18개 관절의 속도 제한 후 목표–응답 각도에 대해 전체 RMS를 계산했다. 실제 로봇 측정값은 아니다.

## 문헌

1. U. Saranli, M. Buehler, D. E. Koditschek, **RHex: A Simple and Highly Mobile Hexapod Robot**, *The International Journal of Robotics Research*, 20(7), 616–631, 2001. [연구기관 원문 PDF](https://www.ri.cmu.edu/pub_files/pub4/saranli_uluc_2001_1/saranli_uluc_2001_1.pdf). Table 1, 논문 p.617의 `V (m/s)` 열에서 RHex 0.55를 확인했다. 표 주석은 V를 최대 속도로 정의한다.
2. P. Čížek et al., **Design, Construction, and Rough-Terrain Locomotion Control of Novel Hexapod Walking Robot With Four Degrees of Freedom Per Leg**, *IEEE Access*, 2021. DOI: [10.1109/ACCESS.2021.3053492](https://doi.org/10.1109/ACCESS.2021.3053492). [저자 연구실 원문 PDF](https://comrob.fel.cvut.cz/papers/access21hantr.pdf). Table 1의 `Maximum speed [m s−1]` 열에서 PhantomX AX 0.29와 HAntR 0.43을 확인했다. PhantomX 값은 해당 표가 기존 문헌에서 인용한 값이고, HAntR은 이 연구에서 제안한 플랫폼이다.

## 해석 제한

- 속도는 각 논문의 해당 플랫폼에 대해 보고된 값이다. 크기·질량·관절 구조·제어기·지면 조건이 다르며 현재의 최신 최고 성능을 의미하지 않는다.
- 현재 Classical 모델은 몸체가 월드에 고정되어 실제 주행 최대 속도를 평가할 수 없다. 내부 위치 추정기의 전진 평균 속도 **0.2349 m/s**를 실제 속도 막대에 넣거나 최대 속도로 바꾸지 않았다.
- 문헌의 발끝·관절 RMS가 ‘미확보’인 것은 동일 정의의 수치를 선택 출처에서 확보하지 못했다는 뜻이다. 해당 로봇이 부정확하거나 해당 연구 전반에 평가가 없다는 뜻이 아니다.
- 전진 평균 속도와 최대 속도, 가상 IMU와 실제 몸체 흔들림, 발끝 높이 변화폭과 장애물 극복 높이를 서로 대체하지 않는다.
- 따라서 ‘현재 로봇이 기존 로봇보다 몇 % 우수하다’거나 ‘Residual-RL로 개선되었다’는 결론은 이 자료로 내릴 수 없다.

## 재생성

이 폴더에서 MATLAB 함수 `make_figure_08`을 실행하면 `metrics.json`과 코드에 명시된 문헌 수치를 이용해 PNG, FIG, CSV를 다시 만든다. CSV의 `NaN`은 미평가 또는 미확보 값이다. 원래 Simulink 모델은 변경하거나 재실행하지 않는다.

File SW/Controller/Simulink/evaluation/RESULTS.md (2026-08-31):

# MATLAB/Simulink 실행 결과

2026-08-31에 기존 `plant.slx`를 MATLAB R2026a Update 3에서 직접 실행했다. 원래 입력과 제어 상수를 유지한 **0–81초 시험 1회**이며, 실제 실행에는 약 105.6초가 걸렸다. 202개 신호를 기록했다. 모델과 파라미터 원본은 수정하지 않았다.

**이번 결과는 몸체가 월드에 고정된 관절·기구학 제어 시험이다. 실제 자유 보행이나 험지 주행 성능을 입증하는 결과는 아니다.**

**최신 요청 반영:** 기존 실행의 VirtualIMU 값으로 가상 자세 RMSE 표와 사진 8을 채웠다. 아래 그림과 표에 가상 신호임을 명시하며, 실제 몸체의 보행 안정성은 여전히 미평가이다. [가상 자세 비교와 해석 범위](BODY_STABILITY_COMPARISON.md)에 계산 구간과 문헌 기준값을 정리했다.

## 보고서에 넣을 그림

### 사진 7. MATLAB/Simulink 발끝 궤적 및 추종 결과

[PNG 원본](figure_07_foot_trajectory.png) · [MATLAB 편집 파일](figure_07_foot_trajectory.fig)

권장 캡션:

> 사진 7. MATLAB/Simulink 기반 6족 로봇의 발끝 궤적 및 추종 결과. 기존 모델의 전진 명령 구간(7 ≤ t < 10 s)에서 발끝 목표와 관절 동역학 응답으로 계산한 정기구학 위치를 비교하였다. 6개 다리의 3차원 발끝 RMS 오차는 3.39 mm이다. 몸체 고정 모델에서 얻은 제어 시험 결과이며 지형 통과 성능을 의미하지 않는다.

왼쪽 위는 1번 다리의 8–9초 궤적이며, 나머지 패널은 전진 명령 구간 전체를 사용한다. 좌표는 몸체 좌표계이다. 목표는 `BodyPosturePIOverlay` 출력, 응답은 `FK_Leg2Body` 출력이다. 접촉 센서로 측정한 발 위치가 아니다.

### 기존 제어기 결과 보조 그림

[PNG 원본](classical_control_results.png) · [MATLAB 편집 파일](classical_control_results.fig)

권장 캡션:

> 기존 Classical Controller의 가상 자세 응답 및 관절 추종 결과. 상단은 81초 시험의 Roll·Pitch 기준과 VirtualIMU 출력을, 하단은 전진 구간의 대표 관절 응답과 18개 관절의 RMS 오차를 나타낸다. VirtualIMU는 자세 명령에서 생성되므로 실제 몸체 흔들림이나 자세 안정성을 검증한 결과로 해석할 수 없다.

### 사진 8. Classical Controller 가상 자세와 기존 6족 로봇의 참고값

[PNG 원본](figure_08_body_attitude_comparison.png) · [MATLAB 편집 파일](figure_08_body_attitude_comparison.fig) · [수치 CSV](body_attitude_comparison.csv) · [가상 IMU 요약](virtual_imu_metrics.json)

| 대상 | Roll RMSE (°) | Pitch RMSE (°) | 데이터 유형 |
|---|---:|---:|---|
| 우리 Classical | 0.000 | 0.000 | 명령 기반 VirtualIMU, 7 ≤ t < 10 s |
| HexWalker II, Tripod | 0.390 | 0.366 | 문헌의 실제 로봇 시험 |

우리 가상 출력은 이 전진 구간에서 0°로 유지되므로 RMSE가 0이다. 실제 몸체 안정성이나 외부 로봇 대비 우위를 뜻하지 않는다.

> 사진 8. 기존 Classical Controller의 명령 기반 VirtualIMU에서 산출한 Roll·Pitch RMSE와 HexWalker II의 문헌 실측 참고값. 우리 값은 기존 Simulink 실행의 전진 명령 구간(7 ≤ t < 10 s), 문헌값은 Zhang et al. (2021), Table 5의 Tripod 실험을 사용했다. 가상 신호와 실제 몸체 측정값은 데이터 생성 방식과 시험 조건이 다르므로 실제 보행 안정성의 우열이나 개선율을 나타내지 않는다.

재생성 명령은 `make_body_stability_figure`이다. 기존 원본 MAT를 후처리하며 새 보행 시험이나 동역학 모델 실행을 수행하지 않는다.

### 이전 사진 8 — 속도·추종 지표 참고 그림

[PNG 원본](figure_08_hexapod_comparison.png) · [MATLAB 편집 파일](figure_08_hexapod_comparison.fig) · [비교 수치 CSV](hexapod_comparison.csv) · [출처와 비교 조건](COMPARISON_SOURCES.md)

사용자의 변경 요청에 따라 **현재 Classical Controller의 시뮬레이션 측정값과 대표 6족 로봇의 공개 문헌 수치**를 비교한다. Residual-RL 비교나 설계 구조도가 아니다.

권장 캡션:

> 사진 8. 현재 Classical Controller의 제어 정확도와 대표 6족 로봇의 문헌 성능 비교. 현재 모델의 발끝·관절 RMS 추종 오차는 각각 3.385 mm와 0.400°이며, RHex·PhantomX AX·HAntR의 보고된 최대 주행 속도는 각각 0.55·0.29·0.43 m/s이다. 모델과 시험 조건이 다르므로 직접적인 우열 판단에는 사용할 수 없다.

RHex 속도는 [Saranli et al. (2001), Table 1](https://www.ri.cmu.edu/pub_files/pub4/saranli_uluc_2001_1/saranli_uluc_2001_1.pdf), PhantomX AX 및 HAntR 속도는 [Čížek et al. (2021), Table 1](https://comrob.fel.cvut.cz/papers/access21hantr.pdf)에 근거한다. 해당 논문의 로봇 세대와 시험에서 보고한 값으로, 각 플랫폼의 최신 최고 성능을 뜻하지 않는다.

현재 모델의 0.2349 m/s는 위치 추정기 출력에서 계산한 평균값이므로 **실제 주행 최대 속도 막대에서는 제외**했다. 문헌 로봇의 동일 정의 RMS 수치를 확보하지 못한 곳은 ‘미확보’, 현재 모델의 자유 주행 시험은 ‘미평가’로 표시한다. 결측값은 0이나 성능 부족을 의미하지 않는다.

## 실제로 산출한 제어 시험 수치

| 평가항목 | 결과 | 산출 범위 |
|---|---:|---|
| 6개 다리 통합 발끝 RMS 거리 오차 | **3.385 mm** | 전진 명령 구간, 7 ≤ t < 10 s |
| 발끝 최대 거리 오차 | **8.631 mm** | 같은 구간, 6개 다리 중 최대 |
| 18개 관절 통합 RMS 오차 | **0.4004°** | 같은 구간, 속도 제한 후 목표 대비 |
| 6개 다리 모두 IK 유효인 표본 비율 | **100%** | 0–81 s, 200 Hz 평가 표본 |
| 제어기 Fault 발생 | **없음** | 이번 시험 1회 |
| 가상 전복 Fault 발생 | **없음** | 실제 전복 시험이 아님 |

발끝 오차는 각 다리의 `norm(응답 XYZ - 목표 XYZ)`이다. 통합 RMS는 여섯 다리와 평가 시간 표본 전체의 제곱평균제곱근으로 계산했다. 관절 통합 RMS는 18개 관절의 라디안 오차를 도 단위로 변환해 같은 방식으로 계산했다. 목표 신호에 시간 지연 보정이나 위상 맞춤을 적용하지 않았다.

| 다리 | 발끝 RMS 오차 (mm) | 최대 오차 (mm) | 발끝 Z 변화폭 (cm) |
|---|---:|---:|---:|
| 1 | 3.256 | 8.283 | 21.918 |
| 2 | 3.331 | 8.319 | 21.958 |
| 3 | 3.542 | 8.631 | 22.033 |
| 4 | 3.298 | 8.271 | 21.919 |
| 5 | 3.308 | 8.326 | 21.954 |
| 6 | 3.562 | 8.622 | 22.007 |

발끝 Z 변화폭은 몸체 좌표계에서 전진 구간의 `max(Z)-min(Z)`이다. **약 22 cm라는 값을 최대 극복 단차로 사용하면 안 된다.**

## 요청한 최종 성능표의 현재 평가 상태

| 평가항목 | 최종 결과 | 이유 |
|---|---|---|
| 평지 10 m 보행 성공률 | 미평가 | 자유 보행 10 m 시험 및 10회 반복 없음 |
| 평균 보행 속도 | 미평가 | 실제 몸체 이동량을 측정할 수 없는 고정 몸체 모델 |
| 최대 극복 단차 | 미평가 | 단차와 접촉 동역학을 이용한 통과 시험 없음 |
| 최대 등판 경사 | 미평가 | 경사면 주행 시험 없음 |
| 계단 통과 성공률 | 미평가 | 계단 시험 및 10회 반복 없음 |
| 최대 Roll 변동 **(가상 신호)** | **33.677°** | 전체 0–81 s 최대–최소, 의도적 자세 변경 포함; 실제 몸체 미평가 |
| 최대 Pitch 변동 **(가상 신호)** | **34.965°** | 전체 0–81 s 최대–최소, 의도적 자세 변경 포함; 실제 몸체 미평가 |
| Classical Controller 험지 성공률 | 미평가 | 지형·성공 판정·반복 시험 없음 |
| Residual-RL 험지 성공률 | 미평가 | 학습 정책과 비교 시험을 확인하지 못함 |
| 평균 경로 추종 오차 | 실제 경로 기준 미평가 | 내부 위치 추정값은 있으나 독립적인 실제 몸체 경로 없음 |
| 장애물 탐지 성공률 | 미평가 | 이 모델에 탐지 평가 입력·정답 데이터 없음 |
| 장애물 회피 성공률 | 미평가 | 이 모델에 회피 경로·충돌 판정 시험 없음 |

미평가는 0%나 실패를 뜻하지 않는다. 이 항목들을 임의 숫자로 채우지 않았다.

## 가상·추정 신호 참고값

아래 값은 CSV에서 실제로 계산됐지만 위 표의 실보행 성능을 대체하지 못한다.

| 내부 신호 평가항목 | 값 | 의미 |
|---|---:|---|
| 위치 추정기 기준 전진 평균 x 속도 | 0.2349 m/s | 7.000–9.995 s의 추정 x 변위 / 경과 시간 |
| 내부 XY 위치 기준–추정값 평균 차이 | 0.01004 m | 7 ≤ t < 10 s, 두 축 거리 평균 |
| 가상 Roll 최대 절댓값 | 18.0789° | 0–81 s, 의도적인 자세 변경 포함 |
| 가상 Pitch 최대 절댓값 | 27.8354° | 0–81 s, 의도적인 자세 변경 포함 |
| 가상 Roll 최대–최소 변화폭 | 33.6774° | 0–81 s, peak-to-peak |
| 가상 Pitch 최대–최소 변화폭 | 34.9651° | 0–81 s, peak-to-peak |

`Plant/VirtualIMU`는 지연된 자세 명령을 Roll·Pitch 출력으로 반환한다. `Plant/MATLAB Function1`의 `TestContact`는 보행 위상과 시간으로 접촉 신호를 생성한다. `World Frame → Rigid Transform4 → Rigid Transform7 → Body` 연결에는 몸체가 자유 이동할 관절이 없다. 따라서 위치 추정기가 이동량을 출력하더라도 실제 몸체 이동량은 아니다. 이 모델의 수치는 별도로 변경된 STM32 펌웨어 상수와도 구분해야 한다.

## 데이터와 재현

| 파일 | 내용 |
|---|---|
| `simulation_raw.mat` | Simulink SimulationOutput 원본, 신호 목록, 실행 소요 시간 |
| `signals_200Hz.csv` | 0–81초, 0.005초 간격의 202개 신호와 시간 열 |
| `signal_map.csv` | 각 CSV 열의 원본 블록 경로와 출력 포트 |
| `foot_metrics.csv` | 다리별 발끝 RMS·최대 오차·Z 변화폭 |
| `joint_metrics.csv` | 18개 관절의 RMS 오차, 다리 1의 관절 1–3부터 순서대로 배열 |
| `metrics.json` | 조건과 한계를 포함한 주요 수치 |
| `simulation_log.txt` | 실행 시작·종료 및 MATLAB 버전 기록 |
| `model_functions.txt` | 실행 당시 SLX 내부 MATLAB 함수의 읽기 전용 추출본 |
| `run_evaluation.m` | 기존 모델을 저장하지 않고 로깅을 추가해 실행 |
| `export_evaluation.m` | 저장된 MAT에서 CSV·수치·그림 재생성 |

CSV와 위 수치는 원시 신호를 200 Hz 공통 시간축으로 선형 보간해 계산했다. 중복 시각은 마지막 값을 사용했고, 전체 신호의 시간 범위와 유한수 여부를 검사했다. 원래 가변 시간 간격의 데이터는 MAT에 보존했다. 후처리에는 추가 Statistics Toolbox가 필요하지 않다.

MATLAB에서 이 폴더를 현재 폴더로 선택한 뒤 실행한다.

```matlab
run_evaluation
export_evaluation
```

그림만 다시 만들 때는 `export_evaluation`만 실행한다. `plant.slx`가 이미 열려 있다면 미저장 작업을 먼저 보관하고 별도의 MATLAB 세션에서 실행한다. 실행 스크립트는 모델을 저장하지 않고 닫는다.

실행에 사용한 원본의 SHA-256:

- `plant.slx`: `10B2DF43606460FBF9658EE338C4FB42BB2C1FBD3513F292A4D7DAAB6C56ABF3`
- `plant_parameters.m`: `46E7ABFF286E2CE896B79EB7C3372D5CD4C5525D4DFC44FF4FF3D457DB767943`

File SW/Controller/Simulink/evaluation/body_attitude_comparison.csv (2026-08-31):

Robot | RollRMSE_deg | PitchRMSE_deg | Evidence | Source
Our Classical - VirtualIMU | 0 | 0 | Command-derived virtual signal; not physical stability | simulation_raw.mat; 7 <= t < 10 s
HexWalker II - Tripod | 0.39 | 0.366 | Physical robot experiment; Zhang et al. 2021, Table 5 | https://www.mdpi.com/2076-3417/11/8/3714

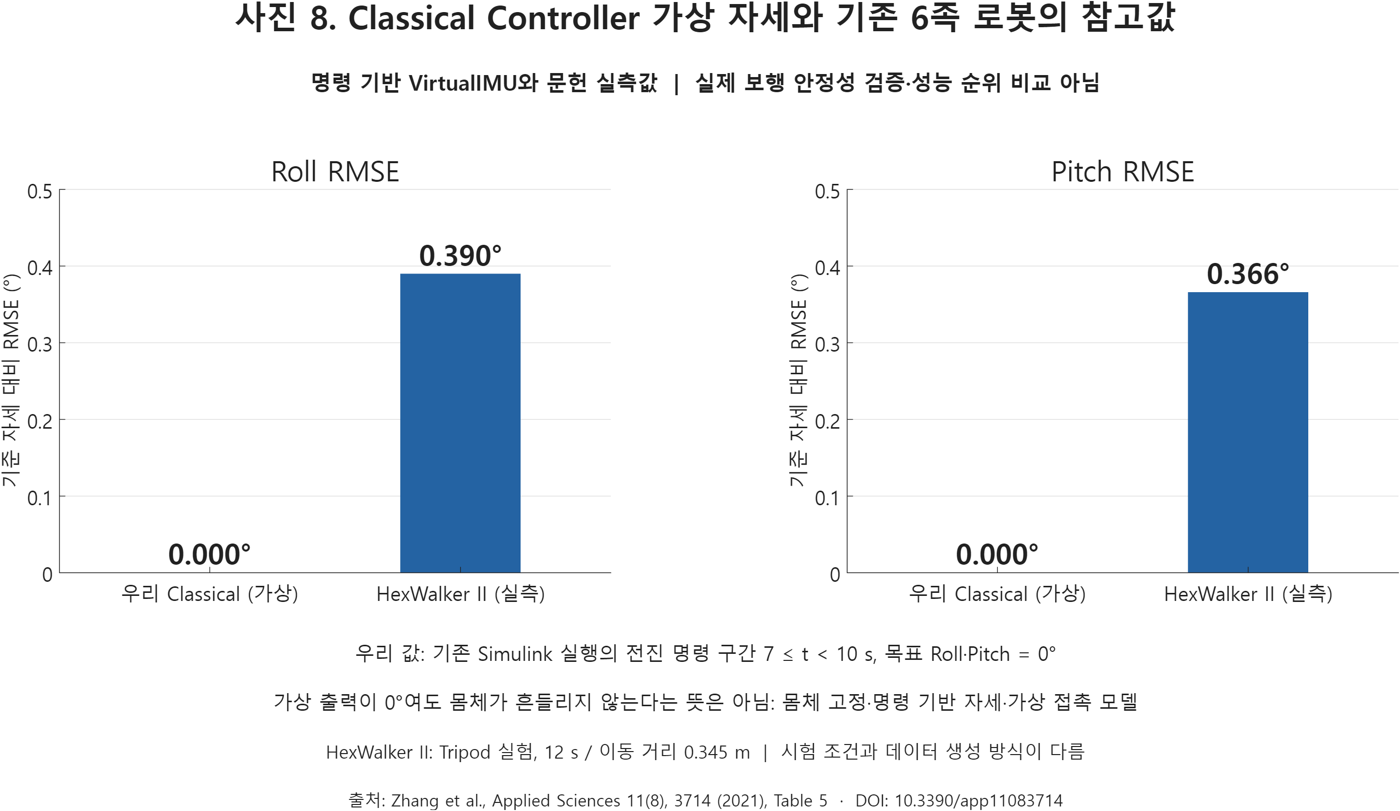
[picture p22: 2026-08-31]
SW/Controller/Simulink/evaluation/figure_08_body_attitude_comparison.png

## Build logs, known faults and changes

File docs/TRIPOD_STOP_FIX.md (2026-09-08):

# 수 회 Tripod 후 정지 수정

짧은 반복 학습과 cycle별 W&B 업로드는 [observe 프로필 명령](ADAPTIVE_OBSERVE_CYCLES.md)을 사용한다.
아래 `fast` 예시는 지형 승급 커리큘럼이며 같은 평지 반복용이 아니다.

## 확인한 원인과 수정

최근 로컬 `adaptive-flat-debug` / `adaptive-flat-fast` 학습 로그에는
`termination/no_progress`가 주된 종료 사유로 기록되어 있었다.
사용자가 본 특정 영상/가중치의 모든 실패를 동일 원인이라고 단정하지 않는다.

`AdaptiveGaitEnv._candidates()`는 classical half-stance 끝점에 예상 몸체
전진·회전까지 추가했다. 반면 실행기는 현재 몸체 좌표로 변환한 끝점을
phase 동안 고정한다. 전진 0.08 m/s, 1초 phase이면 기준점 전진량이
0.04 m여야 하는데 0.12 m가 되는 불일치였다. 이 추가 몸체 변환을 제거해
STM32 `FootTrajectory_BuildNominalPlan`의 half-stance 기준과 맞췄다.
terrain Z 조회, 후보 안전 검사, HOLD, no-progress 종료 조건은 유지한다.

추가 변경:

- Viewer가 checkpoint의 `action_profile`을 복원한다. `flat_safe`로 학습한
  출력을 viewer에서 갑자기 full authority로 실행하지 않는다.
- 공통 checkpoint metadata에도 `action_profile`을 기록한다.
- `policy_video.py`의 잘못된 들여쓰기와 reset 전 미정의 state/action 사용을 수정했다.
- 학습용·공통 GIF 생성기는 같은 이름의 `.termination.json`에 실제 종료 사유,
  성공 여부, 실행 시간과 요청 시간을 남긴다.
- `check_adaptive_rollout.py`는 사용자용 zero-action 진단 도구다. PPO를 실행하지
  않으며, 종료 사유와 완료한 phase 수를 JSON에 저장한다.

## 이미 실행한 확인과 한계

사용자의 검증 위임 지시를 어기고 수정 중 CPU 시뮬레이션을 실행했다.
사용자가 다시 지적한 뒤 시뮬레이션·학습·추가 테스트 실행을 중단했다.

실행했던 조건: flat, oracle, Tripod, action=0, seed=0, 명령 0.08 m/s.

| 항목 | 수정 전 | nominal 수정 후 |
|---|---|---|
| 완료 phase | 3 | 12 (Tripod 6 cycles) |
| 전진 위치 | 약 0.204 m | 약 1.000 m |
| 종료 시간 | 약 7.12초 | 약 14.34초 |
| 종료 | no_progress | 1 m 지형 목표 도달, failure 항목 없음 |

이는 특정 조건의 zero-action baseline 확인이다. 최근 PPO 가중치 재평가,
추가 학습, LiDAR 계단 등판, 실기는 수행하지 않았다. 이후 추가한 진단 도구와
영상 종료 JSON 생성 경로도 실행하지 않았다.

착지점은 phase-entry 몸체 좌표의 끝점이다. world marker와 실제 접촉점의 오차는
몸체 이동·자세 응답의 영향을 받는다. 이 수정으로 험지의 world-locked 착지나
전체 swept-path collision 검증까지 완료된 것은 아니다.

## 사용자가 실행할 명령

먼저 가중치 없이 기본 보행을 확인한다.

```bash
cd /home/huro/Hexapod-Robot-integration
source /home/huro/.venvs/hexapod-mjx/bin/activate
bash scripts/view_foothold_planner.sh --controller adaptive --terrain flat --perception oracle --gait-mode tripod --speed 0.08 --seed 0
```

실시간 viewer가 필요하지 않으면 curriculum 실행이 cycle 종료 후 best-score GIF를 자동 저장한다.

창 없이 동일 baseline의 종료 원인을 기록하려면:

```bash
python mjx/check_adaptive_rollout.py --cpu --perception oracle --terrain-level 0 --speed 0.08 --seed 0 --seconds 20
```

결과는 `mjx/generated/adaptive_baseline.json`에 저장된다. `completed_phases`는
한 Tripod group의 swing 수이므로 2 phase가 한 cycle이다. 1 m 목표 도달 후
`done=true`, `success=true`, 빈 `termination`이면 성공 종료다.
`termination/no_progress`이면 HOLD/전진 정체, tilt/clearance 등은 물리 실패다.

기본 보행을 확인한 뒤 새 출력 디렉터리로 학습한다. 아래 학습은 사용자가 실행한다.

```bash
bash scripts/train_adaptive_gait.sh --stage 1 --terrain-level 0 --perception teacher --action-profile flat_safe --output mjx/runs/adaptive-flat-nominal-fix
```

짧게 반복해 학습 변화만 보려면 아래 한 구간을 사용한다. 16초 episode는 flat에서
여러 Tripod cycle과 전진 정체를 볼 수 있는 최소 길이이고, 4회 평가는 100k step마다
수치를 남긴다. 각 실행은 새 output 경로를 사용한다.

```bash
bash scripts/train_adaptive_gait.sh \
  --stage 1 \
  --terrain-level 0 \
  --perception teacher \
  --action-profile flat_safe \
  --timesteps 400000 \
  --num-envs 128 \
  --batch-size 128 \
  --num-minibatches 4 \
  --episode-length 800 \
  --num-evals 4 \
  --best-video-duration 12 \
  --output mjx/runs/adaptive-flat-observe-01
```

다음 짧은 구간은 `--restore`에 직전 checkpoint 경로를 넣고 output만 바꾼다.

```bash
bash scripts/train_adaptive_gait.sh \
  --stage 1 --terrain-level 0 --perception teacher --action-profile flat_safe \
  --timesteps 400000 --num-envs 128 --batch-size 128 --num-minibatches 4 \
  --episode-length 800 --num-evals 4 --best-video-duration 12 \
  --restore mjx/runs/adaptive-flat-observe-01/checkpoints/<step> \
  --output mjx/runs/adaptive-flat-observe-02
```

여러 짧은 cycle을 자동으로 진행하면서 각 cycle의 최고 score 영상과 전체 최고 score 영상을
남기려면 curriculum runner를 사용한다. 아래는 cycle당 400k step, 16초 episode, 4회 평가다.

```bash
bash scripts/train_adaptive_curriculum.sh \
  --profile fast \
  --perception teacher \
  --run-name adaptive-observe-cycles \
  --timesteps-per-stage 400000 \
  --num-envs 128 \
  --num-evals 4 \
  --episode-length 800 \
  --action-profile flat_safe \
  --best-video-duration 12 \
  --wandb
```

저장 위치는 다음과 같다.

```text
mjx/runs/adaptive-curriculum/adaptive-observe-cycles/
  00_tripod-flat_try00/videos/best.gif       # 해당 cycle 내부 원본
  00_tripod-flat_try00/monitor/best_checkpoint.json # score/checkpoint manifest
  curriculum_history.json                     # cycle별 score/checkpoint/video 경로
```

W&B는 기본 활성화다. 매 평가 결과는 `eval/*`로 즉시 올라가고, 해당 cycle의 최고
score가 갱신될 때마다 `cycle/best_score`, `cycle/best_step`이 즉시 기록된다. cycle이
끝나면 같은 W&B run에 `cycle/best_video`와 checkpoint artifact가 업로드된다.

이전 checkpoint는 source hash가 달라 기존 strict loader에서 거부된다.
자동 호환 처리나 hash 우회는 추가하지 않았다. 이전 학습 결과는 보존하고,
수정된 실행기를 기준으로 새 학습 결과와 비교한다.

## 작업 범위

로컬에 있던 커리큘럼 및 학습 코드 변경은 보존했다. 이번 변경은 로컬 수정이며
추가 commit/push는 수행하지 않았다. STM32 및 기존 18-D 제어기는 수정하지 않았다.

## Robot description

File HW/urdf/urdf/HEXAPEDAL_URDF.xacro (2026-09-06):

<?xml version="1.0" ?>
<robot name="HEXAPEDAL_URDF" xmlns:xacro="http://www.ros.org/wiki/xacro">

<xacro:include filename="$(find HEXAPEDAL_URDF_description)/urdf/materials.xacro" />
<xacro:include filename="$(find HEXAPEDAL_URDF_description)/urdf/HEXAPEDAL_URDF.trans" />
<xacro:include filename="$(find HEXAPEDAL_URDF_description)/urdf/HEXAPEDAL_URDF.gazebo" />
<link name="base_link">
  <inertial>
    <origin xyz="0.00025434395505728345 -0.006770052707082428 -0.01980778635493637" rpy="0 0 0"/>
    <mass value="0.4167268942372759"/>
    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
  </inertial>
  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
</link>

<link name="DXF_Lipo_3s_7200mah_100c_R_1">
  <inertial>
    <origin xyz="2.8449465006019636e-16 -5.507747036226363e-16 0.01899999999999944" rpy="0 0 0"/>
    <mass value="0.43481956000000005"/>
    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
  </inertial>
  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
</link>

<link name="DXF_Lipo_2s_7200mah_100c_1">
  <inertial>
    <origin xyz="2.575717417130363e-16 -5.863365348801608e-16 0.01349999999999954" rpy="0 0 0"/>
    <mass value="0.31407264000000007"/>
    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
  </inertial>
  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
</link>

<link name="DC_Converter_R_1">
  <inertial>
    <origin xyz="3.0531133177191805e-16 -2.7977620220553945e-16 0.008999999999999488" rpy="0 0 0"/>
    <mass value="0.020008620000000005"/>
    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
  </inertial>
  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
</link>

<link name="DC_Converter_L_1">
  <inertial>
    <origin xyz="2.498001805406602e-16 -4.04121180963557e-16 0.008999999999999522" rpy="0 0 0"/>
    <mass value="0.020008620000000005"/>
    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
  </inertial>
  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
</link>

<link name="DXF_Lipo_3s_7200mah_100c_L_1">
  <inertial>
    <origin xyz="3.7470027081099033e-16 -7.728193085476676e-16 0.01899999999999952" rpy="0 0 0"/>
    <mass value="0.43481956000000005"/>
    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
  </inertial>
  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
</link>

<link name="AMASS_XT60_F_FeMale_1_1">
  <inertial>
    <origin xyz="4.403270908240331e-07 -0.0042722788702512365 -0.005825000000000344" rpy="0 0 0"/>
    <mass value="0.0059978303405165"/>
    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
  </inertial>
  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
</link>

<link name="XHP_4_1_1">
  <inertial>
    <origin xyz="-0.020915 -0.112 -0.0227" rpy="0 0 0"/>
    <mass value="0.0"/>
    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
  </inertial>
  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
</link>

<link name="Volt_Meter_1_1">
  <inertial>
    <origin xyz="4.403270944530746e-07 -0.0051176670331799096 -0.010000000000000276" rpy="0 0 0"/>
    <mass value="0.0099955365"/>
    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
  </inertial>
  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
</link>

<link name="XHP_4_2_1">
  <inertial>
    <origin xyz="-0.020915 -0.112 0.0373" rpy="0 0 0"/>
    <mass value="0.0"/>
    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
  </inertial>
  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
</link>

<link name="AMASS_XT60E_F_FeMale_3_1">
  <inertial>
    <origin xyz="4.4032709085872757e-07 -0.004272278870251292 -0.005825000000000472" rpy="0 0 0"/>
    <mass value="0.0059978303405165"/>
    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
  </inertial>
  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
</link>

<link name="XHP_3_1">
  <inertial>
    <origin xyz="-0.020915 -0.112 0.0073" rpy="0 0 0"/>
    <mass value="0.0"/>
    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
  </inertial>
  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
</link>

<link name="AMASS_XT60E_F_FeMale_2_1">
  <inertial>
    <origin xyz="4.4032709084138033e-07 -0.004272278870251223 -0.005825000000000369" rpy="0 0 0"/>
    <mass value="0.0059978303405165"/>
    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
  </inertial>
  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
</link>

<link name="Volt_Meter_2_1">
  <inertial>
    <origin xyz="4.4032709435246065e-07 -0.005117667033180104 -0.01000000000000039" rpy="0 0 0"/>
    <mass value="0.0099955365"/>
    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
  </inertial>
  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
</link>

<link name="Volt_Meter_3_1">
  <inertial>
    <origin xyz="4.403270944600135e-07 -0.00511766703318009 -0.010000000000000453" rpy="0 0 0"/>
    <mass value="0.0099955365"/>
    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
  </inertial>
  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
</link>

<link name="flame2_1">
  <inertial>
    <origin xyz="-0.11049076535099432 -0.012576471461830946 -0.006020172140728458" rpy="0 0 0"/>
    <mass value="0.17303971949014474"/>
    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
  </inertial>
  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
</link>

<link name="STM32_F446RE_1">
  <inertial>
    <origin xyz="4.831204880595408e-16 2.3592239273284576e-16 0.007499999999999691" rpy="0 0 0"/>
    <mass value="0.077009625"/>
    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
  </inertial>
  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
</link>

<link name="Jetson_Orin_Nano_Super_1">
  <inertial>
    <origin xyz="2.3809079707781677e-16 2.393918396847994e-16 0.017999999999999645" rpy="0 0 0"/>
    <mass value="0.17497958400000005"/>
    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
  </inertial>
  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
</link>

<link name="Relay_Module_L_1">
  <inertial>
    <origin xyz="3.191891195797325e-16 0.023500000000000045 0.008999999999999746" rpy="0 0 0"/>
    <mass value="0.02999916"/>
    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
  </inertial>
  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
</link>

<link name="Relay_Module_R_1">
  <inertial>
    <origin xyz="4.163336342344337e-16 -0.023499999999999688 0.00899999999999975" rpy="0 0 0"/>
    <mass value="0.02999916"/>
    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
  </inertial>
  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
</link>

<link name="RB_flame4_1">
  <inertial>
    <origin xyz="-0.020163841378835465 0.020163841393334644 -0.003624618500374904" rpy="0 0 0"/>
    <mass value="0.06395081687871436"/>
    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
  </inertial>
  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
</link>

<link name="RM_flame4_1">
  <inertial>
    <origin xyz="-0.028515733220629627 1.024826445927829e-11 -0.0036246185003594943" rpy="0 0 0"/>
    <mass value="0.06395081687871436"/>
    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
  </inertial>
  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
</link>

<link name="RF_flame4_1">
  <inertial>
    <origin xyz="-0.02016384139333474 -0.020163841378829747 -0.0036246185003646542" rpy="0 0 0"/>
    <mass value="0.06395081687871436"/>
    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
  </inertial>
  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
</link>

<link name="LB_flame4_1">
  <inertial>
    <origin xyz="0.020163841393337184 0.020163841378827235 -0.003624618500364335" rpy="0 0 0"/>
    <mass value="0.06395081687871436"/>
    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
  </inertial>
  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
</link>

<link name="LM_flame4_1">
  <inertial>
    <origin xyz="0.0285157332206301 -1.0254801452447281e-11 -0.0036246185003593165" rpy="0 0 0"/>
    <mass value="0.06395081687871436"/>
    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
  </inertial>
  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
</link>

<link name="LF_flame4_1">
  <inertial>
    <origin xyz="0.020163841378832717 -0.020163841393343346 -0.0036246185003829686" rpy="0 0 0"/>
    <mass value="0.06395081687871436"/>
    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
  </inertial>
  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
</link>

<link name="RF_DS51150_270_1_1">
  <inertial>
    <origin xyz="-0.02303277026668618 -0.023032770253798768 -0.006733285359171658" rpy="0 0 0"/>
    <mass value="0.16496568495572975"/>
    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
  </inertial>
  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
</link>

<link name="RM_DS51150_270_1_1">
  <inertial>
    <origin xyz="-0.03257375316691127 9.103111479469606e-12 -0.006733285359164957" rpy="0 0 0"/>
    <mass value="0.16496568495572975"/>
    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
  </inertial>
  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
</link>

<link name="RB_DS51150_270_1_1">
  <inertial>
    <origin xyz="-0.02303277025380847 0.023032770266688846 -0.006733285359181024" rpy="0 0 0"/>
    <mass value="0.16496568495572975"/>
    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
  </inertial>
  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
</link>

<link name="LF_DS51150_270_1_1">
  <inertial>
    <origin xyz="0.023032770253793314 -0.023032770266692065 -0.0067332853591978185" rpy="0 0 0"/>
    <mass value="0.16496568495572975"/>
    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
  </inertial>
  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
</link>

<link name="LM_DS51150_270_1_1">
  <inertial>
    <origin xyz="0.03257375316691205 -9.109372835345474e-12 -0.006733285359164388" rpy="0 0 0"/>
    <mass value="0.16496568495572975"/>
    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
  </inertial>
  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
</link>

<link name="LB_DS51150_270_1_1">
  <inertial>
    <origin xyz="0.023032770266683683 0.02303277025379316 -0.006733285359171906" rpy="0 0 0"/>
    <mass value="0.16496568495572975"/>
    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
  </inertial>
  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
</link>

<link name="RF_bearing_1_1">
  <inertial>
    <origin xyz="-2.0112892396006998e-07 -2.0112892160084606e-07 -0.0020000000000082105" rpy="0 0 0"/>
    <mass value="0.003999875766550524"/>
    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
  </inertial>
  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
</link>

<link name="RM_bearing_1_1">
  <inertial>
    <origin xyz="6.38378239159465e-16 -5.943443107125054e-15 -0.0019999999999986452" rpy="0 0 0"/>
    <mass value="0.003999875766550524"/>
    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
  </inertial>
  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
</link>

<link name="RB_bearing_1_1">
  <inertial>
    <origin xyz="-2.011289320369425e-07 2.0112892845647323e-07 -0.0020000000000233685" rpy="0 0 0"/>
    <mass value="0.003999875766550524"/>
    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
  </inertial>
  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
</link>

<link name="LF_bearing_1_1">
  <inertial>
    <origin xyz="2.0112893234225382e-07 -2.0112894041912632e-07 -0.0020000000000358793" rpy="0 0 0"/>
    <mass value="0.003999875766550524"/>
    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
  </inertial>
  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
</link>
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

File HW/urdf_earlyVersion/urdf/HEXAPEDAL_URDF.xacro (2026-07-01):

<?xml version="1.0" ?>
<robot name="HEXAPEDAL_URDF" xmlns:xacro="http://www.ros.org/wiki/xacro">

<xacro:include filename="$(find HEXAPEDAL_URDF_description)/urdf/materials.xacro" />
<xacro:include filename="$(find HEXAPEDAL_URDF_description)/urdf/HEXAPEDAL_URDF.trans" />
<xacro:include filename="$(find HEXAPEDAL_URDF_description)/urdf/HEXAPEDAL_URDF.gazebo" />
<link name="base_link">
  <inertial>
    <origin xyz="0.00025434395505728345 -0.006770052707082428 -0.01980778635493637" rpy="0 0 0"/>
    <mass value="0.4167268942372759"/>
    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
  </inertial>
  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
</link>

<link name="LF_motor_horn_1_1">
  <inertial>
    <origin xyz="2.0112883578060625e-07 -2.0112900961377633e-07 -0.0029620014635889577" rpy="0 0 0"/>
    <mass value="0.0019994583976964877"/>
    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
  </inertial>
  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
</link>

<link name="LM_motor_horn_1_1">
  <inertial>
    <origin xyz="6.38378239159465e-16 -1.2255637395598544e-13 -0.002962001463593416" rpy="0 0 0"/>
    <mass value="0.0019994583976964877"/>
    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
  </inertial>
  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
</link>

<link name="LB_motor_horn_1_1">
  <inertial>
    <origin xyz="2.011290100023544e-07 2.0112882784251163e-07 -0.0029620014636008683" rpy="0 0 0"/>
    <mass value="0.0019994583976964877"/>
    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
  </inertial>
  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
</link>

<link name="RF_motor_horn_1_1">
  <inertial>
    <origin xyz="-2.0112901133462202e-07 -2.011288341430273e-07 -0.0029620014635999697" rpy="0 0 0"/>
    <mass value="0.0019994583976964877"/>
    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
  </inertial>
  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
</link>

<link name="RM_motor_horn_1_1">
  <inertial>
    <origin xyz="8.881784197001252e-16 1.160120332257981e-13 -0.0029620014635937213" rpy="0 0 0"/>
    <mass value="0.0019994583976964877"/>
    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
  </inertial>
  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
</link>

<link name="RB_motor_horn_1_1">
  <inertial>
    <origin xyz="-2.0112883852840824e-07 2.0112901186197796e-07 -0.002962001463585443" rpy="0 0 0"/>
    <mass value="0.0019994583976964877"/>
    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
  </inertial>
  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
</link>

<link name="LF_motor_horn_3_1">
  <inertial>
    <origin xyz="0.002093982657406651 0.002094294184112 -1.198336750524813e-13" rpy="0 0 0"/>
    <mass value="0.0019994583976964877"/>
    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
  </inertial>
  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
</link>

<link name="LM_motor_horn_3_1">
  <inertial>
    <origin xyz="6.120430273703903e-10 0.0029620017478611885 -1.204861430465493e-13" rpy="0 0 0"/>
    <mass value="0.0019994583976964877"/>
    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
  </inertial>
  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
</link>

<link name="LB_motor_horn_3_1">
  <inertial>
    <origin xyz="-0.0020942941841195495 0.0020939826573903586 -1.3103147223346533e-13" rpy="0 0 0"/>
    <mass value="0.0019994583976964877"/>
    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
  </inertial>
  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
</link>

<link name="RF_motor_horn_3_1">
  <inertial>
    <origin xyz="-0.0020939826574031817 0.002094294184122325 1.1608196480971957e-13" rpy="0 0 0"/>
    <mass value="0.0019994583976964877"/>
    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
  </inertial>
  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
</link>

<link name="RM_motor_horn_3_1">
  <inertial>
    <origin xyz="-6.12038641989443e-10 0.0029620017478554604 1.2246567287593702e-13" rpy="0 0 0"/>
    <mass value="0.0019994583976964877"/>
    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
  </inertial>
  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
</link>

<link name="RB_motor_horn_3_1">
  <inertial>
    <origin xyz="0.0020942941841201046 0.0020939826574023768 1.291727322381926e-13" rpy="0 0 0"/>
    <mass value="0.0019994583976964877"/>
    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
  </inertial>
  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
</link>

<link name="DXF_Lipo_3s_7200mah_100c_R_1">
  <inertial>
    <origin xyz="2.8449465006019636e-16 -5.507747036226363e-16 0.01899999999999944" rpy="0 0 0"/>
    <mass value="0.43481956000000005"/>
    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
  </inertial>
  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
</link>

<link name="DXF_Lipo_2s_7200mah_100c_1">
  <inertial>
    <origin xyz="2.575717417130363e-16 -5.863365348801608e-16 0.01349999999999954" rpy="0 0 0"/>
    <mass value="0.31407264000000007"/>
    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
  </inertial>
  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
</link>

<link name="DC_Converter_R_1">
  <inertial>
    <origin xyz="3.0531133177191805e-16 -2.7977620220553945e-16 0.008999999999999488" rpy="0 0 0"/>
    <mass value="0.020008620000000005"/>
    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
  </inertial>
  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
</link>

<link name="DC_Converter_L_1">
  <inertial>
    <origin xyz="2.498001805406602e-16 -4.04121180963557e-16 0.008999999999999522" rpy="0 0 0"/>
    <mass value="0.020008620000000005"/>
    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
  </inertial>
  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
</link>
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

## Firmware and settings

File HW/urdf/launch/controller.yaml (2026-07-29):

HEXAPEDAL_URDF_controller:
  # Publish all joint states -----------------------------------
  joint_state_controller:
    type: joint_state_controller/JointStateController
    publish_rate: 50

  # Position Controllers --------------------------------------
  LF_1_position_controller:
    type: effort_controllers/JointPositionController
    joint: LF_1
    pid: {p: 100.0, i: 0.01, d: 10.0}
  LM_1_position_controller:
    type: effort_controllers/JointPositionController
    joint: LM_1
    pid: {p: 100.0, i: 0.01, d: 10.0}
  LB_1_position_controller:
    type: effort_controllers/JointPositionController
    joint: LB_1
    pid: {p: 100.0, i: 0.01, d: 10.0}
  RF_1_position_controller:
    type: effort_controllers/JointPositionController
    joint: RF_1
    pid: {p: 100.0, i: 0.01, d: 10.0}
  RM_1_position_controller:
    type: effort_controllers/JointPositionController
    joint: RM_1
    pid: {p: 100.0, i: 0.01, d: 10.0}
  RB_1_position_controller:
    type: effort_controllers/JointPositionController
    joint: RB_1
    pid: {p: 100.0, i: 0.01, d: 10.0}
  LF_2_position_controller:
    type: effort_controllers/JointPositionController
    joint: LF_2
    pid: {p: 100.0, i: 0.01, d: 10.0}
  LM_2_position_controller:
    type: effort_controllers/JointPositionController
    joint: LM_2
    pid: {p: 100.0, i: 0.01, d: 10.0}
  LB_2_position_controller:
    type: effort_controllers/JointPositionController
    joint: LB_2
    pid: {p: 100.0, i: 0.01, d: 10.0}
  RF_2_position_controller:
    type: effort_controllers/JointPositionController
    joint: RF_2
    pid: {p: 100.0, i: 0.01, d: 10.0}
  RM_2_position_controller:
    type: effort_controllers/JointPositionController
    joint: RM_2
    pid: {p: 100.0, i: 0.01, d: 10.0}
  RB_2_position_controller:
    type: effort_controllers/JointPositionController
    joint: RB_2
    pid: {p: 100.0, i: 0.01, d: 10.0}
  LF_3_position_controller:
    type: effort_controllers/JointPositionController
    joint: LF_3
    pid: {p: 100.0, i: 0.01, d: 10.0}
  LM_3_position_controller:
    type: effort_controllers/JointPositionController
    joint: LM_3
    pid: {p: 100.0, i: 0.01, d: 10.0}
  LB_3_position_controller:
    type: effort_controllers/JointPositionController
    joint: LB_3
    pid: {p: 100.0, i: 0.01, d: 10.0}
  RF_3_position_controller:
    type: effort_controllers/JointPositionController
    joint: RF_3
    pid: {p: 100.0, i: 0.01, d: 10.0}
  RM_3_position_controller:
    type: effort_controllers/JointPositionController
    joint: RM_3
    pid: {p: 100.0, i: 0.01, d: 10.0}
  RB_3_position_controller:
    type: effort_controllers/JointPositionController
    joint: RB_3
    pid: {p: 100.0, i: 0.01, d: 10.0}

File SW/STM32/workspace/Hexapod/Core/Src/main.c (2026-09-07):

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
/* Includes ------------------------------------------------------------------*/
#include "main.h"

/* USER CODE BEGIN Includes */
#include "app/hexapod_app.h"
#include "communication/jetson_spi.h"
#include "measurement/measurement_stage0.h"
#include "measurement/measurement_stage4.h"
#include "measurement/measurement_stage5.h"

/* USER CODE END Includes */

/* USER CODE BEGIN PD */
#define SENSOR_RAW_TEST_MODE         0U  // 세 보행 모드를 포함한 일반 제어 앱을 실행한다.
#define JOINT_ZERO_CALIBRATION_MODE  0U  // 관절 기구학 영점 정렬 모드를 선택한다.
#define JOINT_ADC_CALIBRATION_MODE   0U  // L6 J1 ADC 보정 모드를 선택한다.
#define JETSON_SPI_BRINGUP_TEST      0U  // Jetson SPI 단독 시험 모드를 선택한다.
/* USER CODE END PD */

SPI_HandleTypeDef hspi1;
SPI_HandleTypeDef hspi2;
DMA_HandleTypeDef hdma_spi2_rx;
DMA_HandleTypeDef hdma_spi2_tx;

TIM_HandleTypeDef htim1;
TIM_HandleTypeDef htim2;
TIM_HandleTypeDef htim3;
TIM_HandleTypeDef htim4;
TIM_HandleTypeDef htim5;
TIM_HandleTypeDef htim6;
TIM_HandleTypeDef htim8;

UART_HandleTypeDef huart5;
UART_HandleTypeDef huart2;
UART_HandleTypeDef huart3;
UART_HandleTypeDef huart6;

/* USER CODE BEGIN PV */
#if JETSON_SPI_BRINGUP_TEST
static JetsonSpi_Handle_t g_jetson_spi_test;
static RobotSensorSnapshot_t g_jetson_sensor_test;
#endif
/* USER CODE END PV */

void SystemClock_Config(void);
static void MX_GPIO_Init(void);
static void MX_DMA_Init(void);
static void MX_USART2_UART_Init(void);
static void MX_SPI1_Init(void);
static void MX_SPI2_Init(void);
static void MX_TIM1_Init(void);
static void MX_TIM2_Init(void);
static void MX_TIM3_Init(void);
static void MX_TIM4_Init(void);
static void MX_TIM5_Init(void);
static void MX_TIM6_Init(void);
static void MX_TIM8_Init(void);
static void MX_UART5_Init(void);
static void MX_USART3_UART_Init(void);
static void MX_USART6_UART_Init(void);
/**
  * @brief  The application entry point.
  * @retval int
  */
int main(void)
{

  /* MCU Configuration--------------------------------------------------------*/

  /* Reset of all peripherals, Initializes the Flash interface and the Systick. */
  HAL_Init();

  /* Configure the system clock */
  SystemClock_Config();

  /* Initialize all configured peripherals */
  MX_GPIO_Init();
  MX_DMA_Init();
  MX_USART2_UART_Init();
  MX_SPI1_Init();
  MX_SPI2_Init();
  MX_TIM1_Init();
  MX_TIM2_Init();
  MX_TIM3_Init();
  MX_TIM4_Init();
  MX_TIM5_Init();
  MX_TIM6_Init();
  MX_TIM8_Init();
  MX_UART5_Init();
  MX_USART3_UART_Init();
  MX_USART6_UART_Init();
  /* USER CODE BEGIN 2 */
#if SENSOR_RAW_TEST_MODE
  if (!MeasurementStage0_Init(&huart2, &huart3, &hspi1, &huart6))
  {
    Error_Handler();  // 전체 센서 모드 초기화 오류를 디버거에서 확인한다.
  }
#elif JOINT_ADC_CALIBRATION_MODE
  if (!MeasurementStage5_Init(&hspi1,
                              &htim1,
                              &htim2,
                              &htim3,
                              &htim4,
                              &htim5,
                              &htim8))
  {
    Error_Handler();  // ADC 보정 모드 초기화 오류를 디버거에서 확인한다.
  }
#elif JOINT_ZERO_CALIBRATION_MODE
  if (!MeasurementStage4_Init(&hspi1,
                              &htim1,
                              &htim2,
                              &htim3,
                              &htim4,
                              &htim5,
                              &htim8))
  {
    Error_Handler();  // 영점 모드 초기화 오류를 디버거에서 확인한다.
  }
#elif JETSON_SPI_BRINGUP_TEST
  JetsonSpi_Init(&g_jetson_spi_test, &hspi2);  // 모터 앱 없이 SPI2 통신만 준비한다.
#else
  if (HexapodApp_BoardInit() != HAL_OK)  // 실제 장치와 최종 제어 앱을 시작한다.
  {
    Error_Handler();                        // 초기화 실패 시 출력을 정지한다.
  }
#endif

  /* USER CODE END 2 */

  /* Infinite loop */
  /* USER CODE BEGIN WHILE */
  while (1)
  {
    /* USER CODE END WHILE */

    /* USER CODE BEGIN 3 */
#if SENSOR_RAW_TEST_MODE
    MeasurementStage0_Process();  // GPS·IMU·ADC·조종기 값을 계속 기록한다.
#elif JOINT_ADC_CALIBRATION_MODE
    MeasurementStage5_Process();  // L6 J1의 세 각도 ADC를 자동 측정한다.
#elif JOINT_ZERO_CALIBRATION_MODE
    MeasurementStage4_Process();  // 전체 관절을 보정표 기준 0도로 유지한다.
#elif JETSON_SPI_BRINGUP_TEST
    if (!g_jetson_spi_test.tx_frame_ready)
    {
      (void)JetsonSpi_PrepareSensorFrame(&g_jetson_spi_test,
                                         &g_jetson_sensor_test,
                                         true,
                                         HAL_GetTick());
    }
    (void)JetsonSpi_Process(&g_jetson_spi_test);
#else
    HexapodApp_BoardProcess();  // 통신과 5 ms 제어 요청을 계속 처리한다.
#endif
  }
  /* USER CODE END 3 */
}

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
/* USER CODE BEGIN 4 */

/* UART 수신 완료를 현재 실행 모드에 전달한다. */
void HAL_UART_RxCpltCallback(UART_HandleTypeDef *huart)
{
#if SENSOR_RAW_TEST_MODE
  MeasurementStage0_UartRxCallback(huart);  // GPS·WT931·CRSF의 다음 수신을 준비한다.
#elif !JOINT_ZERO_CALIBRATION_MODE && !JOINT_ADC_CALIBRATION_MODE && !JETSON_SPI_BRINGUP_TEST
  HexapodApp_BoardUartRxCallback(huart);  // 해당 UART의 다음 수신을 준비한다.
#else
  (void)huart;  // UART를 사용하지 않는 시험 모드에서는 처리하지 않는다.
#endif
}

/* UART 송수신 오류를 현재 실행 모드에 전달한다. */
void HAL_UART_ErrorCallback(UART_HandleTypeDef *huart)
{
#if SENSOR_RAW_TEST_MODE
  MeasurementStage0_UartErrorCallback(huart);  // GPS·WT931·CRSF 수신을 복구한다.
#elif !JOINT_ZERO_CALIBRATION_MODE && !JOINT_ADC_CALIBRATION_MODE && !JETSON_SPI_BRINGUP_TEST
  HexapodApp_BoardUartErrorCallback(huart);  // 해당 UART 송수신을 복구한다.
#else
  (void)huart;  // UART를 사용하지 않는 시험 모드에서는 처리하지 않는다.
#endif
}

/* UART 송신 완료를 최종 앱으로 전달한다. */
void HAL_UART_TxCpltCallback(UART_HandleTypeDef *huart)
{
#if !SENSOR_RAW_TEST_MODE && !JOINT_ZERO_CALIBRATION_MODE && \
    !JOINT_ADC_CALIBRATION_MODE && !JETSON_SPI_BRINGUP_TEST
  HexapodApp_BoardUartTxCpltCallback(huart);  // 해당 UART의 다음 송신을 허가한다.
#else
  (void)huart;  // 센서·보정 시험 모드에서 UART 송신 콜백을 사용하지 않는다.
#endif
}

/* 압력·제어 Timer 완료를 최종 앱으로 전달한다. */
void HAL_TIM_PeriodElapsedCallback(TIM_HandleTypeDef *htim)
{
#if !SENSOR_RAW_TEST_MODE && !JOINT_ZERO_CALIBRATION_MODE && \
    !JOINT_ADC_CALIBRATION_MODE && !JETSON_SPI_BRINGUP_TEST
  HexapodApp_BoardTimerCallback(htim);  // TIM6 압력·제어 실행을 요청한다.
#else
  (void)htim;  // 센서·보정 시험 모드에서 제어 타이머 콜백을 사용하지 않는다.
#endif
}

/* USER CODE END 4 */
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


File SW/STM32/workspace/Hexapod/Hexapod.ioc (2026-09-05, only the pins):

Mcu.UserName=STM32F446RETx
PA0-WKUP.Signal=S_TIM5_CH1
PA1.Signal=S_TIM5_CH2
PA10.Signal=S_TIM1_CH3
PA11.Signal=S_TIM1_CH4
PA12.GPIO_Label=INB2
PA12.Signal=GPIO_Output
PA13.GPIO_Label=TMS
PA13.Signal=SYS_JTMS-SWDIO
PA14.GPIO_Label=TCK
PA14.Signal=SYS_JTCK-SWCLK
PA15.Signal=S_TIM2_CH1_ETR
PA2.Signal=USART2_TX
PA3.Signal=USART2_RX
PA4.GPIO_Label=CS1
PA4.Signal=GPIO_Output
PA5.Signal=SPI1_SCK
PA6.Signal=SPI1_MISO
PA7.Signal=SPI1_MOSI
PA8.Signal=S_TIM1_CH1
PA9.Signal=S_TIM1_CH2
PB0.Signal=S_TIM3_CH3
PB1.Signal=S_TIM3_CH4
PB10.Signal=S_TIM2_CH3
PB12.Signal=SPI2_NSS
PB13.Signal=SPI2_SCK
PB14.Signal=SPI2_MISO
PB15.Signal=SPI2_MOSI
PB2.GPIO_Label=INC2
PB2.Signal=GPIO_Output
PB3.Signal=S_TIM2_CH2
PB4.Signal=S_TIM3_CH1
PB5.Signal=S_TIM3_CH2
PB6.Signal=S_TIM4_CH1
PB7.Signal=S_TIM4_CH2
PB8.Signal=S_TIM4_CH3
PB9.Signal=S_TIM4_CH4
PC0.GPIO_Label=CS2
PC0.Signal=GPIO_Output
PC1.GPIO_Label=CS3
PC1.Signal=GPIO_Output
PC10.Signal=USART3_TX
PC11.Signal=USART3_RX
PC12.Signal=UART5_TX
PC2.GPIO_Label=INA1
PC2.Signal=GPIO_Output
PC3.GPIO_Label=INB1
PC3.Signal=GPIO_Output
PC4.GPIO_Label=INC1
PC4.Signal=GPIO_Output
PC5.GPIO_Label=INA2
PC5.Signal=GPIO_Output
PC6.Signal=USART6_TX
PC7.Signal=USART6_RX
PC8.Signal=S_TIM8_CH3
PC9.GPIO_Label=DRDY
PC9.Signal=GPIO_Output
PD2.Signal=UART5_RX

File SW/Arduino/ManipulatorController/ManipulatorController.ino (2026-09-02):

#include <Servo.h>
#include <EEPROM.h>
#include <math.h>
#include <string.h>

/*
 * Arduino Uno manipulator controller
 *
 * Servo signal pins:
 *   J1~J6 = D5, D6, D7, D8, D9, D10
 * IMPORTANT:
 * - Servo power never comes from the Uno 5 V pin.
 * - HOME_US and SERVO_DIRECTION must be checked on the real arm.
 * - UART diagnostics are printed on D1/TX and the USB Serial Monitor.
 */

namespace Config {

constexpr uint8_t JOINT_COUNT = 6;
constexpr uint8_t SERVO_PIN[JOINT_COUNT] = {5, 6, 7, 8, 9, 10};

// Measured software-zero fallback values. A completed J1~J6 calibration
// stored by ManipulatorCalibration overrides all six values at boot.
constexpr int16_t DEFAULT_HOME_US[JOINT_COUNT] = {
  1290, 1600, 1480, 1510, 1610, 1540
};
int16_t HOME_US[JOINT_COUNT] = {
  1500, 1500, 1500, 1500, 1500, 1500
};

constexpr int16_t CALIBRATION_MIN_US = 1000;
constexpr int16_t CALIBRATION_MAX_US = 2000;
constexpr uint16_t CALIBRATION_MAGIC = 0x4D43;
constexpr uint8_t CALIBRATION_VERSION = 1;
constexpr int CALIBRATION_MAGIC_ADDRESS = 0;
constexpr int CALIBRATION_VERSION_ADDRESS = 2;
constexpr int CALIBRATION_DATA_ADDRESS = 4;

// Change only the corresponding value to -1 if that joint moves backwards.
constexpr int8_t SERVO_DIRECTION[JOINT_COUNT] = {
  +1, +1, -1, +1, +1, +1
};

// J1~J4: DS51150-270, J5~J6: SPT5435LV-180.
constexpr float US_PER_DEG[JOINT_COUNT] = {
  2000.0f / 270.0f,
  2000.0f / 270.0f,
  2000.0f / 270.0f,
  2000.0f / 270.0f,
  2000.0f / 180.0f,
  2000.0f / 180.0f
};

// Conservative software pulse limits. Widen only after one-joint testing.
constexpr int16_t MIN_US[JOINT_COUNT] = {600, 600, 600, 600, 800, 800};
constexpr int16_t MAX_US[JOINT_COUNT] = {2400, 2400, 2400, 2400, 2200, 2200};

// Approximate folded ARM-ready pose based on image 2.
// J1 base, J2 shoulder, J3 elbow, J4 wrist pitch, J5 wrist roll, J6 gripper.
// This is deliberately conservative; it is not a measured Fusion joint export.
constexpr float READY_DEG[JOINT_COUNT] = {
  0.0f, +35.0f, -100.0f, -25.0f, 0.0f, 0.0f
};

constexpr float JOINT_MIN_DEG[JOINT_COUNT] = {
  -90.0f, -10.0f, -125.0f, -120.0f, -90.0f, 0.0f
};
constexpr float JOINT_MAX_DEG[JOINT_COUNT] = {
  +90.0f, +80.0f,  -20.0f,  +60.0f, +90.0f, 45.0f
};

// Measure joint-axis distances in Fusion and replace these two values.
// They affect Cartesian speed/IK response, not the initial ready pose.
constexpr float LINK1_MM = 300.0f;
constexpr float LINK2_MM = 300.0f;

// Controller motion limits. IK converts these Cartesian velocities into
// coordinated J1~J4 motion while keeping the tool pitch approximately fixed.
constexpr float MAX_XZ_SPEED_MM_S = 90.0f;
constexpr float MAX_Y_SPEED_MM_S = 70.0f;
constexpr float MAX_WRIST_SPEED_DEG_S = 50.0f;
constexpr float MAX_JOINT_SPEED_DEG_S = 38.0f;
constexpr float AXIS_FILTER_ALPHA = 0.18f;
constexpr int16_t AXIS_DEADBAND = 35;

constexpr float GRIPPER_OPEN_DEG = 0.0f;
constexpr float GRIPPER_CLOSED_DEG = 35.0f;

constexpr uint16_t CONTROL_PERIOD_MS = 20;
constexpr uint16_t ATTACH_INTERVAL_MS = 250;
constexpr uint16_t HOME_HOLD_MS = 2000;
constexpr uint16_t PAYLOAD_TIMEOUT_MS = 100;
constexpr uint16_t DEBUG_PERIOD_MS = 500;
// At 20 ms/cycle, the longest READY<->HOME travel takes about 7.4 s toward
// HOME and about 3.0 s toward READY. Active control is faster but still slew
// limited separately for the heavy arm joints and the wrist/gripper.
constexpr int16_t HOME_SLEW_US_PER_CYCLE = 2;
constexpr int16_t READY_SLEW_US_PER_CYCLE = 5;
constexpr int16_t ACTIVE_SLEW_US_PER_CYCLE[JOINT_COUNT] = {
  6, 6, 6, 6, 10, 8
};

}  // namespace Config

// Semantic payload used by the arm controller. The transport packet layout,
// framing, CRC and receive code will be connected later.
struct ManipulatorPayload {
  int16_t throttle;
  int16_t yaw;
  int16_t roll;
  int16_t pitch;
  uint8_t sa;
  uint8_t sc;
  uint8_t flags;
  uint8_t switches;
  bool armMode;
  bool controlEnabled;
  bool kill;
  bool fault;
};

namespace UartProtocol {

constexpr uint8_t PACKET_SIZE = 16;
constexpr uint8_t SYNC_0 = 0xA5;
constexpr uint8_t SYNC_1 = 0x5A;
constexpr uint8_t VERSION = 0x01;
// Flags bit 0: controller connected, bit 1: motion armed,
// bit 2: STM32 ARM mode allowed. Switches.SC must also equal 1.
constexpr uint8_t REQUIRED_SAFETY_FLAGS = 0x07;

uint16_t crc16CcittFalse(const uint8_t *data, uint8_t length) {
  uint16_t crc = 0xFFFFU;

  for (uint8_t i = 0; i < length; ++i) {
    crc ^= static_cast<uint16_t>(data[i]) << 8U;

    for (uint8_t bit = 0; bit < 8; ++bit) {
      crc = (crc & 0x8000U)
                ? static_cast<uint16_t>((crc << 1U) ^ 0x1021U)
                : static_cast<uint16_t>(crc << 1U);
    }
  }

  return crc;
}

int16_t readI16LE(const uint8_t *data) {
  const uint16_t raw = static_cast<uint16_t>(data[0]) |
                       (static_cast<uint16_t>(data[1]) << 8U);
  return static_cast<int16_t>(raw);
}
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

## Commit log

2026-07-01 Update STM32F446RE 설정 정리본.md
2026-07-01 여태까지 한 거
    [AMASS_XT60E_F_FeMale_2.stl, AMASS_XT60E_F_FeMale_2_1.stl, AMASS_XT60E_F_FeMale_3.stl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]
2026-07-13 PCB 파일 추가
    [park_kicad-B_Cu.gbr, park_kicad-B_Fab.gbr, park_kicad-B_Mask.gbr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]
2026-07-28 작업한 내역
2026-07-28 add foot stl
    [foot_1_output.stl, foot_2_output.stl, foot_3_output.stl]
2026-07-29 new urdf export
    [AMASS_XT60E_F_FeMale_2.stl, AMASS_XT60E_F_FeMale_2_1.stl, AMASS_XT60E_F_FeMale_3.stl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]
2026-07-31 fix urdf
    [HEXAPEDAL_URDF.urdf, HEXAPEDAL_URDF.xacro, LB_DS51150_270_2_1.stl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]
2026-08-03 sensor test
2026-08-06 초기자세 설정
2026-08-06 좌표축 수정
2026-08-06 좌표축 완성
2026-08-06 좌표축 완성 최최종
2026-08-07 add sensor folder
2026-08-07 좌표축 수정중
2026-08-07 좌표축 완성 + 드론 조종기 입력 설정
2026-08-08 add relay
2026-08-13 제어기 이론 완성
2026-08-14 7단계 보충
2026-08-15 8단계, 급격한 초기 자세 전환으로 오차 발생
2026-08-17 12단계
2026-08-18 9단계, 10단계
2026-08-18 11단계
2026-08-18 제어기 1차 완성본
2026-08-24 제이기 2차 완성본
2026-08-24 md 파일 정리
2026-08-24 코드 구조 정리
2026-08-24 stm32 기본 코드
2026-08-24 실측 및 테스트 코드 작성
2026-08-24 STM32 Jetson SPI 32바이트 통신 추가
2026-08-25 0단계 gps 말곤 다 성공
2026-08-25 1단계 성공
2026-08-25 2단계 성공
2026-08-25 3단계 성공
2026-08-25 4단계 성공
2026-08-25 젯슨 stm 통신 패킷 설정
2026-08-25 5단계 성공
2026-08-25 발 접촉 상태를 SPI 패킷에 추가
2026-08-25 6단계 성공
2026-08-25 캘리브레이션 완료 (GPS·LoRa 실기 검증 미완료, Jetson SPI 패킷 구현·명령 미정, 암·자율주행 미구현)
2026-08-26 알고리즘 테스트 1단계 성공
2026-08-26 알고리즘 테스트 1~10 단계 성공
2026-08-26 최종코드 1차 완성본
2026-08-26 U3 / U6 까지 완료, 조종기 입시값 코드 사용
2026-08-26 압력센서 캘리브레이션 다시 함
2026-08-26 U4 성공!!!!
2026-08-26 개버그 터진 U6 최종본 세이프 파일
2026-08-26 6U 절반의 성공
2026-08-28 stm32 코드 완성
2026-08-29 통신 문제
2026-08-29 수정1회차
2026-08-29 fix(stm32): run full app with stable Jetson SPI DMA
    [main.c]
2026-08-29 urdf change
    [HEXAPEDAL_URDF.xacro, LB_DS51150_270_2_1.stl, LB_DS51150_270_3_1.stl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]
2026-08-29 fix(urdf): align Livox frame with Fusion axes
    [HEXAPEDAL_URDF.xacro]
2026-08-29 임시 세이브파일
2026-08-30 stm32 제어기 코드 최종 완성
2026-08-30 stm32 완성본에 맞춰 md파일 업데이트
2026-08-30 feat(urdf): update model and Livox frame
    [HEXAPEDAL_URDF.xacro, LB_foot_1_1.stl, LB_foot_2_1.stl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]
2026-08-30 통신 레전드 디버깅 성공
2026-08-30 stm32 최종 코드 수정 1차
    [Hexapod.ioc, main.c, robot_config.h]
2026-08-30 feat(urdf): update Livox model with aligned frame
    [HEXAPEDAL_URDF.xacro, livox_mid_360_1.stl]
2026-08-30 압력센서 캘리 다시함
2026-08-31 세이브 파일
    [body_attitude_comparison.csv, foot_metrics.csv, hexapod_comparison.csv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]
2026-09-02 Add calibrated Arduino manipulator controller
2026-09-02 Document Arduino manipulator setup and operation
2026-09-05 Update URDF for revised lidar and camera mount
    [HEXAPEDAL_URDF.xacro, M_column_1_1.stl, M_column_3_fix_1.stl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]
2026-09-05 Update URDF for simplified lidar assembly
    [HEXAPEDAL_URDF.xacro, LB_link2_1.stl, LB_motor_horn_3_1.stl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]
2026-09-05 gps복구 및 보행 딜레이 개선
2026-09-06 험지 보행 개선
2026-09-06 Add single-leg wave gait to middle S1 range
2026-09-06 한발 보행 구현
2026-09-06 강화학습 모드 추가
2026-09-06 Update URDF for revised lidar mount
    [HEXAPEDAL_URDF.xacro, LB_DS51150_270_2_1.stl, LB_DS51150_270_3_1.stl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]
2026-09-06 Connect adaptive execution to app safety and explicit SPI v3 frames
2026-09-06 Add Jetson geometry adapter and portable cross-language contract checks
2026-09-06 Document integration v4 architecture, wire format and user validation handoff
2026-09-06 Keep short classical gait moving through the initial LiDAR blind zone
2026-09-07 캘리브레이션 완료
2026-09-07 Add SPI v3 sensor and GPS transfer
    Expand the STM32-Jetson full-duplex transaction to 64 bytes, with independent 32-byte SENSOR and GPS subframes on MISO and a 64-byte COMMAND frame on MOSI. Add GPS packing, command parsing, protocol 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
2026-09-07 Add RC command-conditioned training with signed velocity and yaw objectives
2026-09-07 Pin curriculum retries to isolated committed sources
2026-09-07 Rewrite README around current RC command tracking workflow
2026-09-07 Default to forward terrain completion without RC yaw commands
2026-09-07 Show current policy each evaluation and shorten preview interval
2026-09-08 Train hybrid gait across terrain curriculum from the first stage
2026-09-08 Preserve local calibration tuning and rough walk verification
2026-09-14 imu yaw 보정 끔, 압력센서 개선, 착지동작 개선
2026-09-27 Add Fusion-exported URDF v2 with Livox origin
    [AMASS_XT60E_F_FeMale_2.stl, AMASS_XT60E_F_FeMale_3.stl, AMASS_XT60_F_FeMale_1.stl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]

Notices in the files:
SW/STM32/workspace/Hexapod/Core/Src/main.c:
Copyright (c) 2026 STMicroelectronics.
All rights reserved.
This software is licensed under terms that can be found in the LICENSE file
